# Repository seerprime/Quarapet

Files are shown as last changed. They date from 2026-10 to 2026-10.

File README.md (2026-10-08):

<div align="center">

# 🐾 QUARAPET

### An 8-servo, Wi-Fi-controlled, DIY quadruped robot with a face that has feelings.

*3D-printed. ESP32-S3 powered. Hand-soldered. Fully open source.*

<br>







<br>

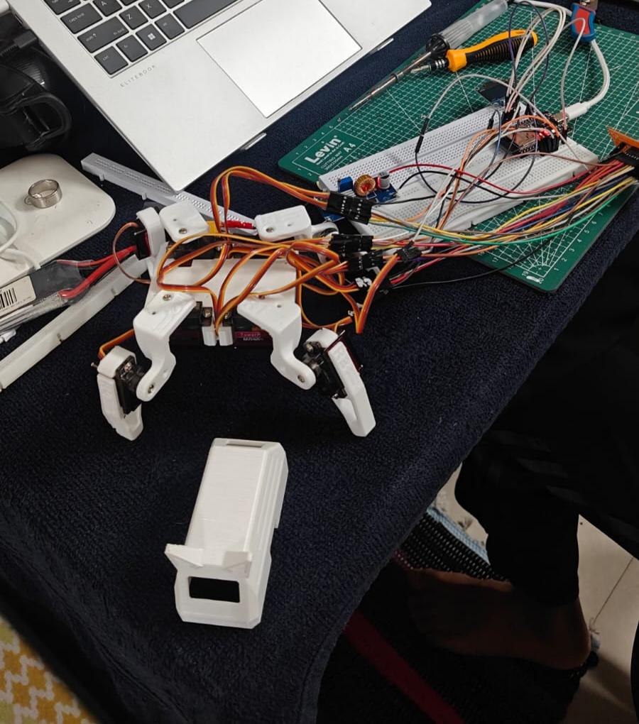
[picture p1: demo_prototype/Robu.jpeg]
Quarapet prototype on the workbench


<sub><i>The prototype mid-build: legs on, wires everywhere, laptop open. This is how it actually happens. 😄</i></sub>

<br><br>

**[🎬 Watch the demo](demo_prototype/prefinshed_build_demo.mp4)** &nbsp;•&nbsp;
**[⚡ Quick Start](#-quick-start)** &nbsp;•&nbsp;
**[🧰 Build Guide](#-build-it-yourself)** &nbsp;•&nbsp;
**[🎮 Controls](#-controls--moves)** &nbsp;•&nbsp;
**[🗂 Repo Map](#-repo-map)**

</div>

---

## 👀 What is Quarapet?

**Quarapet** is a pocket-sized four-legged robot pet that walks, dances, waves, does pushups, plays dead, and expresses its mood on a tiny OLED face.

Power it on and it spins up its **own Wi-Fi network**. Connect with your phone, a **captive portal pops open**, and you're driving a robot dog from your browser. No app, no Bluetooth pairing, no nonsense.

It's built to be **cheap, hackable, and buildable at home** with a 3D printer, a soldering iron, and a free weekend.

---

## ✨ Features

| | |
|---|---|
| 🦿 **8-DOF quadruped** | Two servos per leg for real walking, turning, and crab-stepping |
| 📡 **Self-hosted Wi-Fi AP** | Creates its own hotspot with a **captive portal**, so the control page auto-opens |
| 🏠 **Optional home Wi-Fi mode** | Join your own network from the web UI; reach it via `quarapet-robot.local` |
| 😎 **Animated OLED face** | 38 face sets with multi-frame animations: moods, talking variants, idle blinks |
| 🕺 **20+ built-in moves** | Walk, dance, wave, swim, pushup, bow, worm, moonwalk-ish chaos, and more |
| 🔌 **REST-style API** | `/api/command`, `/api/status`, `/api/wifi/*`, so you can script it or plug it into other things |
| 🎚️ **Live servo subtrim** | Calibrate each servo from the web UI without re-flashing |
| 🔋 **Battery powered** | Single 850 mAh LiPo, onboard switch, decoupling cap on the servo rail |
| 🖨️ **Fully printable** | Every structural part ships as an STL, with a cat-ear top cover 🐱 |

---

## 🎮 Controls & Moves

Everything is triggered from the web UI (or via `/cmd` and `/api/command`).

| Category | Commands |
|---|---|
| 🚶 **Locomotion** | `forward` · `backward` · `left` · `right` |
| 🧍 **Poses** | `stand` · `rest` · `dead` |
| 🎉 **Show-off** | `dance` · `wave` · `bow` · `cute` · `freaky` · `shake` · `shrug` |
| 💪 **Tricks** | `pushup` · `point` · `swim` · `worm` · `crab` |

### 😶 The Face Engine

The OLED isn't just a status light. It runs a frame-based animation system with **38 face sets**:

`happy` · `sad` · `angry` · `surprised` · `sleepy` · `love` · `excited` · `confused` · `thinking` · `idle` · `idle_blink` · plus a matching **`talk_*`** variant for each mood, and a face for every move (`walk`, `dance`, `wave`, `dead`, `crab`...).

When idle, Quarapet blinks on its own. When nobody's touched it for a while, it scrolls its Wi-Fi credentials across the screen so you never forget how to connect. 🙌

---

## ⚡ Quick Start

### 1. Flash the firmware

1. Install the **Arduino IDE** with the **ESP32 board package**.
2. Install these libraries from the Library Manager:
   - `ESP32Servo`
   - `Adafruit GFX Library`
   - `Adafruit SSD1306`
3. Open [`qurapet_firmware/sesame-firmware-main.ino`](qurapet_firmware/sesame-firmware-main.ino). The three `.h` files in the same folder load automatically.
4. Select your ESP32 board, pick the port, and hit **Upload**.

> ⚠️ **Check your pins!** The `servoPins[]` array near the top of the `.ino` is set for a specific board. If you wire to different GPIOs (see the [schematic](schematic/circuit_diagram.pdf)), update that array to match. Servo order is `R1, R2, L1, L2, R4, R3, L3, L4`.

### 2. Power on & connect

| | |
|---|---|
| 📶 **Wi-Fi name** | `quarapet` |
| 🔑 **Password** | `12345678` |
| 🌐 **Address** | `192.168.4.1` (the captive portal should open automatically) |

> 🔒 Change `AP_SSID` and `AP_PASS` in the firmware before you take it anywhere public.

### 3. Drive it 🚗

Tap a button. Watch it move. Smile at the tiny face. That's the whole product.

### 🏠 Want it on your home Wi-Fi?

Use the Wi-Fi setup panel in the web UI (it scans and connects at runtime), or set `NETWORK_SSID`, `NETWORK_PASS` and `ENABLE_NETWORK_MODE true` in the firmware. Then reach it at **`http://quarapet-robot.local`**.

---

## 🧰 Build It Yourself

### 1️⃣ Print the parts

All STLs live in [`cad_files/`](cad_files). Printed in white PLA in the prototype.

| Part | Files |
|---|---|
| 🦴 **Body frame** | `Internal-Frame-v121.stl` |
| 🔽 **Bottom cover** | `Bottom-Cover-v121.stl` |
| 🐱 **Top cover (cat ears!)** | `Top-Cover-Cat-v100.stl` |
| 🦵 **Left legs** | `L1` · `L2` · `L3` · `L4` (`-v117`) |
| 🦵 **Right legs** | `R1` · `R2` · `R3` · `R4` (`-v117`) |

### 2️⃣ Gather the parts

<details>
<summary><b>🔌 Electronics BOM</b> (click to expand)</summary>

<br>

| Component | Qty | Details |
|---|:---:|---|
| **TowerPro MG90S Servo** | 8 | Metal-gear micro servo |
| **ESP32-S3-N16R8** | 1 | Main controller |
| **LiPo Battery** | 1 | 850 mAh |
| **Power Switch** | 1 | ON/OFF |
| **OLED Display** | 1 | 0.96″ SSD1306 (I²C) |
| **Electrolytic Capacitor** | 1 | 100 µF, 25 V (10 V+ is fine) |

Full list: [`BOM/Electronics/parts.md`](BOM/Electronics/parts.md)

</details>

<details>
<summary><b>🔧 Tools & hardware BOM</b> (click to expand)</summary>

<br>

| Item | Spec |
|---|---|
| Phillips screws | M3 × 2.5 mm and M3 × 3 mm |
| Precision screwdriver kit | Multi-bit |
| Hot glue gun | Strain relief and wire fixing |
| Soldering iron + solder | Electronics grade |
| Perfboard | 5 × 7 cm |
| 3-pin headers | For servo connectors |

Full list with safety notes: [`BOM/mechanical_parts/mech_parts.md`](BOM/mechanical_parts/mech_parts.md)

</details>

### 3️⃣ Build the servo power board

Eight servos pull serious current, so they get a dedicated power rail with a bulk capacitor instead of leeching from the ESP32. The board is a simple perfboard distribution unit: **8 × 3-pin headers**, one shared **+ rail**, one shared **GND rail**, a **100 µF cap**, and a **2-pin power input**.

<div align="center">

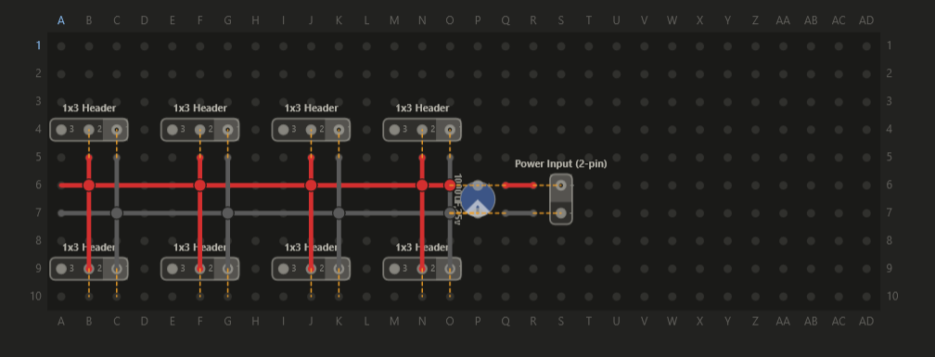
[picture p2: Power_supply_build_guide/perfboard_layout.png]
Perfboard layout for the servo power distribution board


<sub><i>Perfboard layout: red is +V, grey is GND. Follow the grid coordinates.</i></sub>

<br><br>

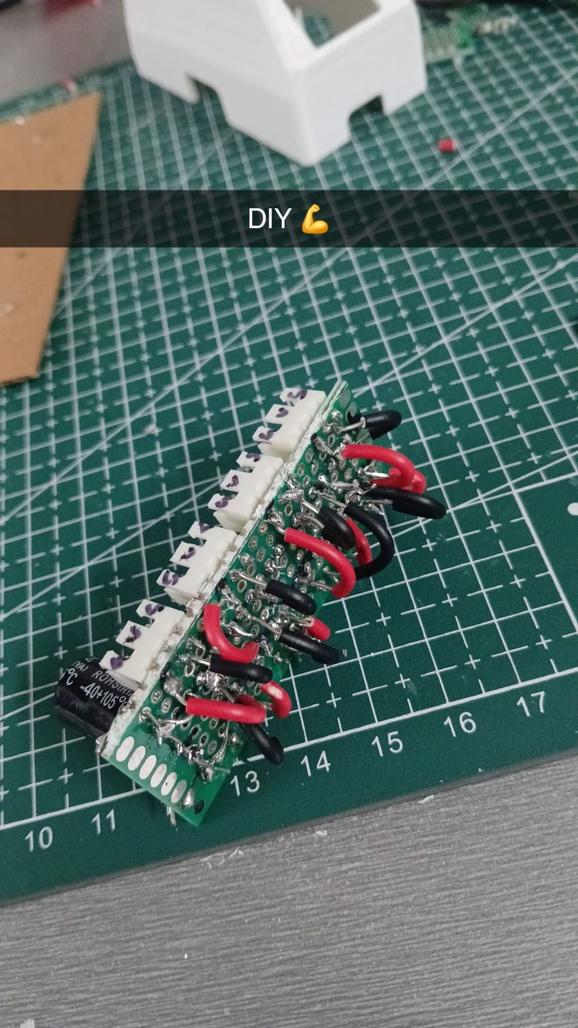
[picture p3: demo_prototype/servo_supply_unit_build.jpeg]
Finished hand-soldered servo supply board


<sub><i>The finished board, hand-soldered. Pure DIY. 💪</i></sub>

</div>

> 💡 **Golden rule:** servo power comes from the battery/regulated supply, **not** from the ESP32's 3.3 V pin. Servo GND and ESP32 GND **must be shared**.

### 4️⃣ Wire it up

Follow the full wiring diagram: **[`schematic/circuit_diagram.pdf`](schematic/circuit_diagram.pdf)**

| Connection | Pin |
|---|---|
| OLED **SDA** | GPIO 17 |
| OLED **SCL** | GPIO 18 |
| 8× servo signal | See `servoPins[]` in firmware |
| Servo V+ / GND | Perfboard power rail |

### 5️⃣ Assemble, flash, calibrate

1. Mount servos in the frame with the M3 screws.
2. Center all servos (run `stand`) *before* attaching the leg horns.
3. Fit the legs, tidy the wires, hot-glue the strain relief.
4. Close up with the cat-ear cover.
5. Fine-tune any crooked legs using **subtrim** in the web UI.

---

## 🎬 See It Move

<div align="center">

**[▶️ Click here to watch the prototype demo](demo_prototype/prefinshed_build_demo.mp4)**

</div>

---

## 🗂 Repo Map

```
Quarapet/
├── 📁 BOM/
│   ├── Electronics/parts.md          # Electronic components list
│   └── mechanical_parts/mech_parts.md # Tools, screws & materials
├── 📁 Power_supply_build_guide/
│   └── perfboard_layout.png          # Servo power board layout
├── 📁 cad_files/                     # 11 printable STL parts
├── 📁 demo_prototype/                # Build photos + demo video
├── 📁 qurapet_firmware/
│   ├── sesame-firmware-main.ino      # Main firmware: Wi-Fi, web server, servos
│   ├── movement-sequences.h          # Walk, dance, pushup & friends
│   ├── face-bitmaps.h                # OLED face animation frames
│   └── captive-portal.h              # Web control UI
└── 📁 schematic/
    └── circuit_diagram.pdf           # Full wiring schematic
```

---

## 🛠️ Hack It

- 🎨 **Add a new face:** add a bitmap to `face-bitmaps.h` and register it in `FACE_LIST`.
- 🕹️ **Add a new move:** write a `runYourPose()` in `movement-sequences.h` and hook it up in the command handler.
- 🤖 **Automate it:** hit `POST /api/command` from a script, a bot, or a smart-home hub.
- ⏱️ **Tune the feel:** tweak `frameDelay`, `walkCycles` and `motorCurrentDelay` for faster or smoother motion.

---

## 🧯 Safety

- Never solder with the battery connected.
- Use a stable iron stand and ventilate your workspace.
- Treat LiPo batteries with respect: no puncturing, no shorting, no unattended charging.
- Hot glue and soldering irons both burn. Be careful.

---

## 🤝 Contributing

Found a bug, improved a gait, or drew a better face? **PRs and issues are very welcome.** Fork it, break it, make it cooler. 🔥

---

## 🙏 Credits

Built with ❤️ by **[@seerprime](https://github.com/seerprime)**.
Thankyou **(https://github.com/dorianborian/sesame-robot/)** for inspiration
Shoutout to the open-source robotics and maker community whose quadruped designs and firmware ideas inspired this build.

---

<div align="center">

### ⭐ If Quarapet made you smile, drop a star! ⭐

*Build it. Break it. Make it yours.* 🐾

</div>

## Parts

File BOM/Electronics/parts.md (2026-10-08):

| Component | Quantity | Specification / Details |
|---|:---:|---|
| **TowerPro MG90S Servo** | 8 | Metal Gear Micro Servo |
| **ESP32-S3-N16R8** | 1 | Main controller |
| **LiPo Battery** | 1 | 850 mAh |
| **Power Switch** | 1 | ON/OFF switch |
| **OLED Display** | 1 | 0.96″ SSD1306 |
| **Electrolytic Capacitor** | 1 | 100 µF, 25 V *(10 V or higher is acceptable)* |

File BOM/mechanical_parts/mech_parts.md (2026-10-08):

# 🔧 Tools & Hardware

This section contains the tools, fasteners, and electronic assembly materials required for the project.

## 📋 Bill of Materials

| S. No. | Item | Specification / Size | Purpose |
|---:|---|---|---|
| 1 | Phillips Head Screw | **M3 × 2.5 mm** | Mounting and securing components |
| 2 | Phillips Head Screw | **M3 × 3 mm** | Mounting and securing components |
| 3 | Screwdriver Kit | Precision / Multi-bit | Tightening and loosening screws |
| 4 | Glue Gun | Standard hot-melt glue gun | Mechanical fixing and insulation |
| 5 | Soldering Wire | Electronics-grade solder | Electrical connections |
| 6 | Perfboard | **5 × 7 cm** | Permanent circuit assembly |
| 7 | 3-Pin Header | Male/Female, 3-pin | Connecting modules and components |
| 8 | Soldering Iron | Electronics soldering iron | Soldering electrical connections |

## 🛠️ Usage

### M3 × 2.5 mm & M3 × 3 mm Screws
Used for securing small mechanical components, brackets, servos, and structural parts.

### Screwdriver Kit
Used for assembling and disassembling the mechanical structure and tightening Phillips-head screws.

### Glue Gun
Used for:
- Securing loose wires
- Strain relief
- Holding lightweight components
- Additional mechanical support

### Soldering Wire & Soldering Iron
Used together to create permanent electrical connections between components mounted on the perfboard and headers.

### 5 × 7 cm Perfboard
Provides a compact platform for permanently mounting and interconnecting electronic components.

### 3-Pin Header
Used to provide detachable connections for sensors, servos, modules, or other peripherals.

## ⚠️ Safety Notes

- Allow the soldering iron to heat up on a stable stand.
- Avoid touching the soldering iron tip or recently soldered joints.
- Use adequate ventilation while soldering.
- Handle the hot glue gun carefully to avoid burns.
- Check screw lengths before installation to prevent damage to internal components.
- Disconnect the power supply before modifying or soldering the circuit.

## 📦 Assembly Checklist

- [ ] M3 × 2.5 mm screws
- [ ] M3 × 3 mm screws
- [ ] Screwdriver kit
- [ ] Glue gun
- [ ] Soldering wire
- [ ] 5 × 7 cm perfboard
- [ ] 3-pin headers
- [ ] Soldering iron

---
**Note:** These tools and materials are intended for the mechanical assembly and electrical integration of the project.

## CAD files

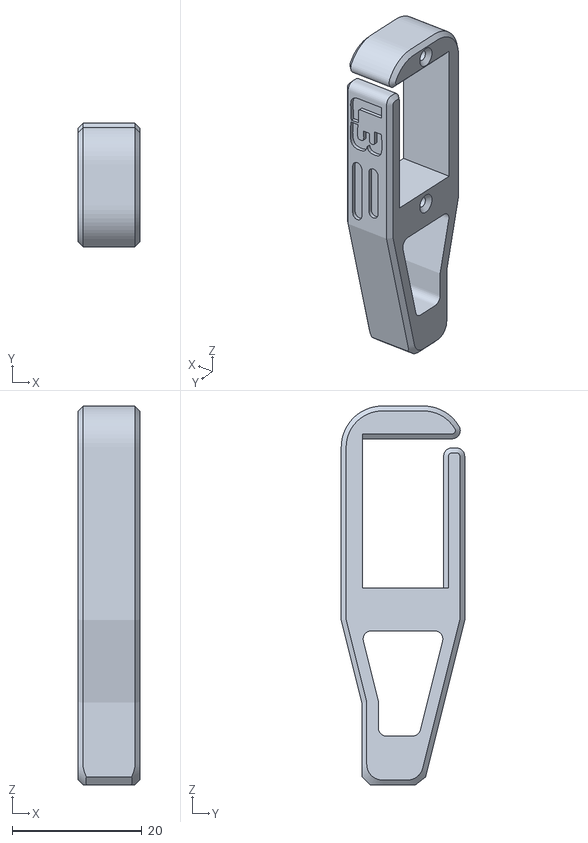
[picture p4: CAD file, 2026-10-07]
cad_files/L3-v117.stl
9.53 x 19.0 x 58.4

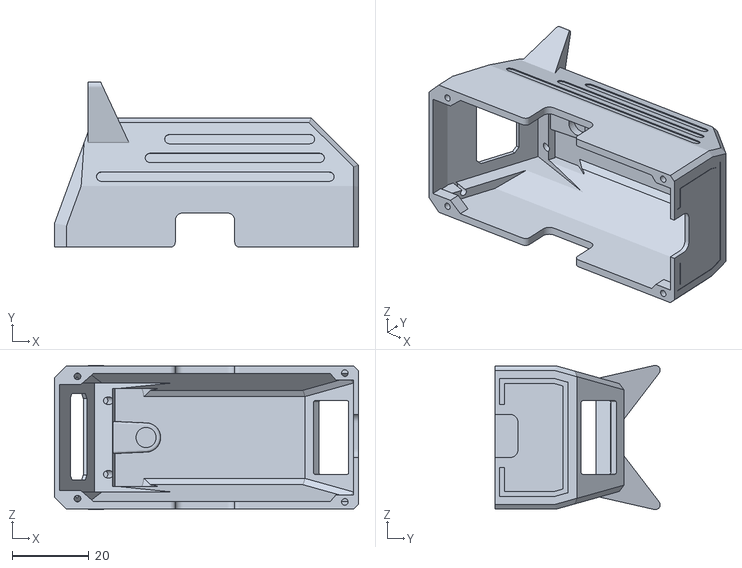
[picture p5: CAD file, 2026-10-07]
cad_files/Top-Cover-Cat-v100.stl
79.2 x 43.1 x 37.6

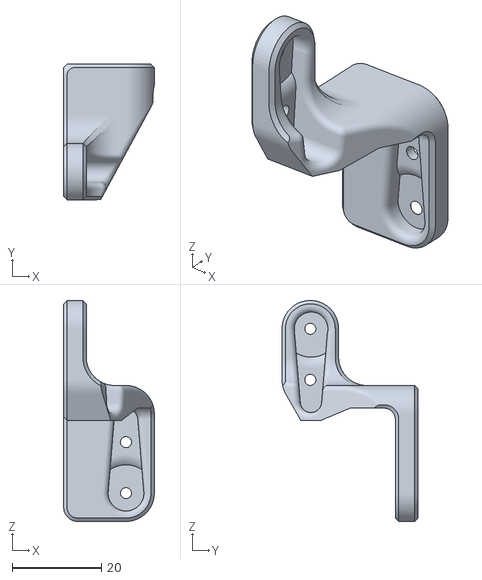
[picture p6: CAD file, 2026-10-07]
cad_files/L2-v117.stl
20.3 x 30.5 x 49.5

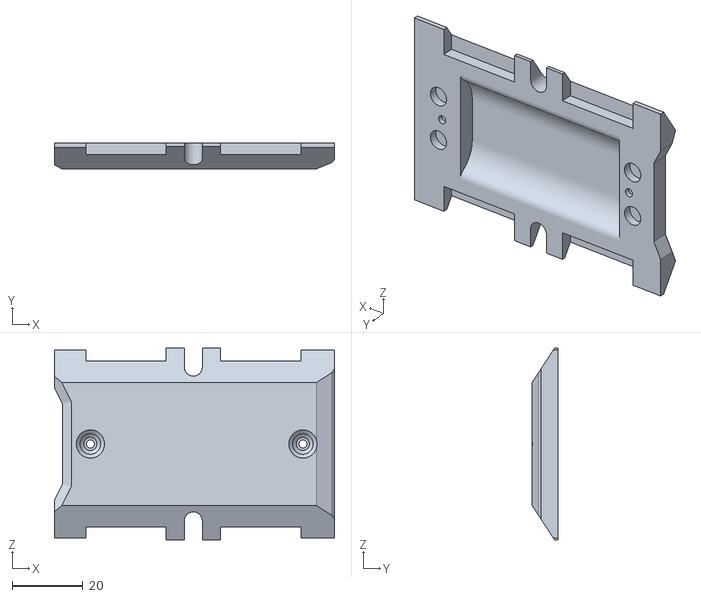
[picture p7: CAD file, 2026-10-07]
cad_files/Bottom-Cover-v121.stl
79.2 x 7.27 x 54.2

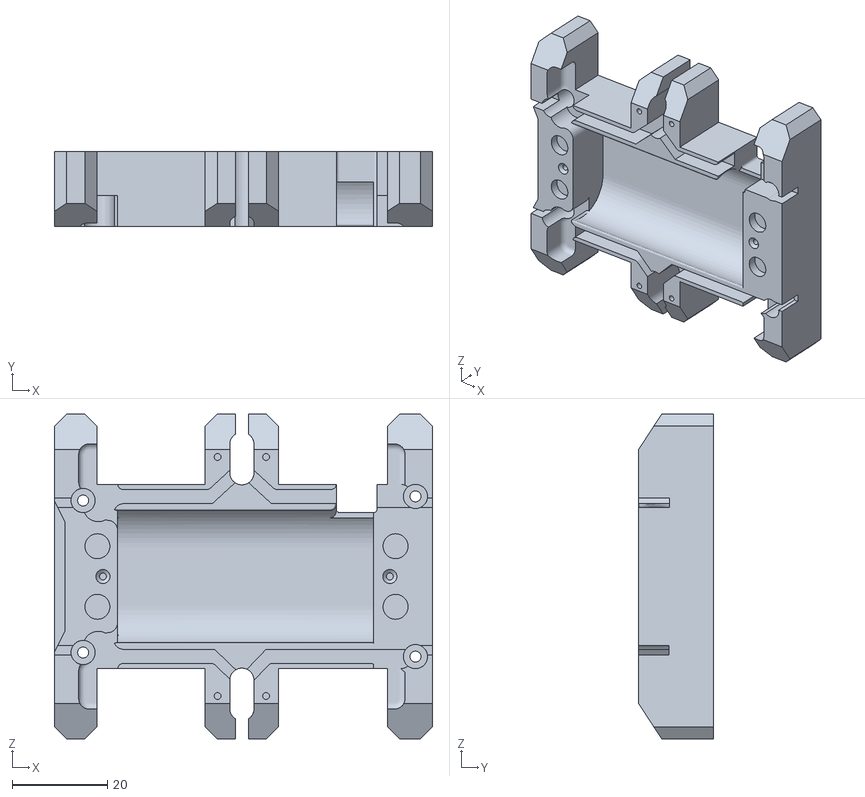
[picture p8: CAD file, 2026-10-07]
cad_files/Internal-Frame-v121.stl
79.2 x 15.7 x 68.1

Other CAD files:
cad_files/L4-v117.stl
cad_files/R3-v117.stl
cad_files/R4-v117.stl
cad_files/L1-v117.stl
cad_files/R2-v117.stl
cad_files/R1-v117 (1).stl

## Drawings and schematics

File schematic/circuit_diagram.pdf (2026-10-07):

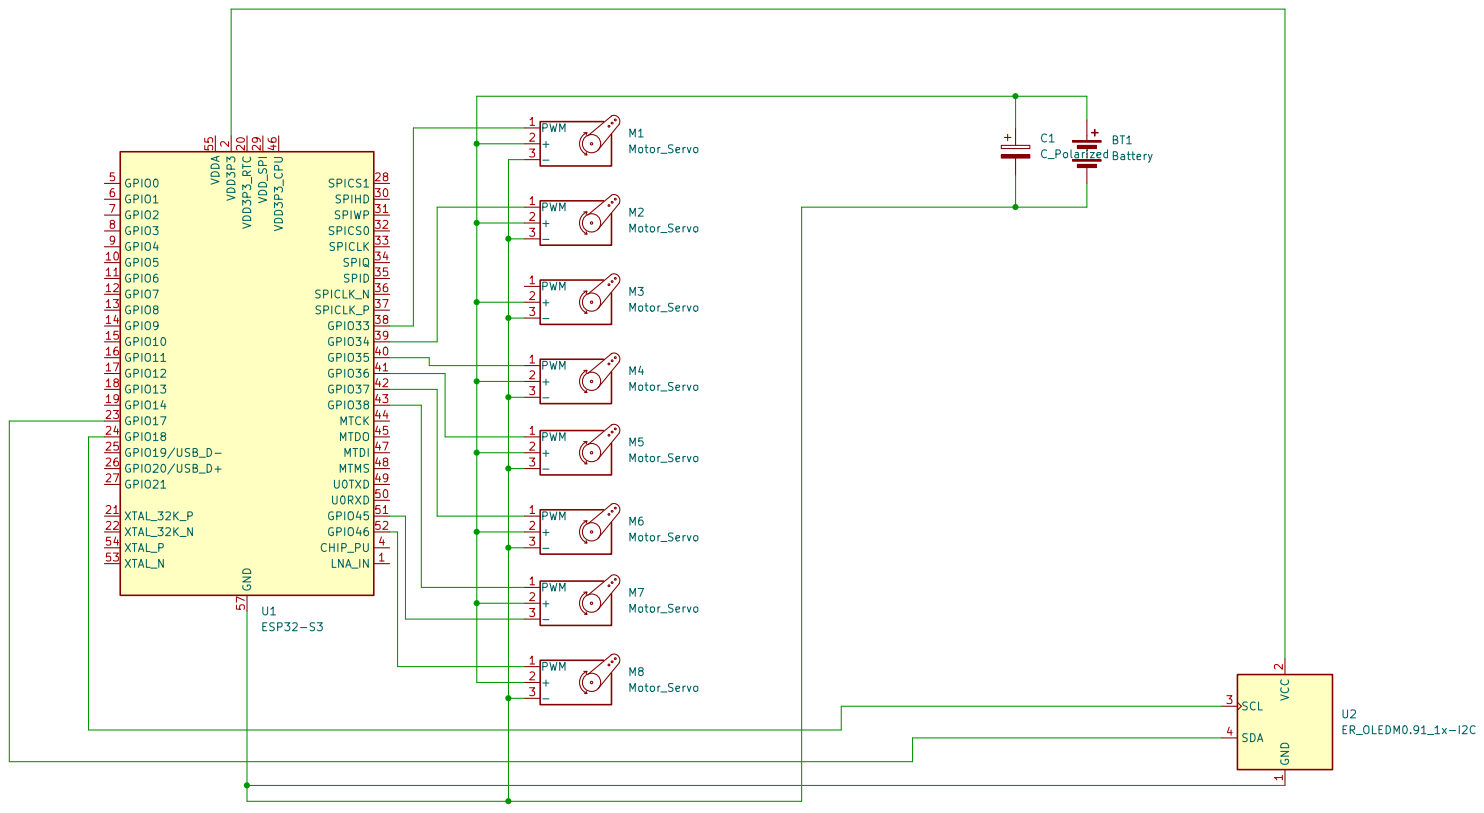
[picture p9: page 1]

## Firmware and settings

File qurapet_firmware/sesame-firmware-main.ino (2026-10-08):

#include <WiFi.h>
#include <WebServer.h>
#include <DNSServer.h>
#include <ESPmDNS.h>
#include <Wire.h>
#include <ESP32Servo.h>
#include <Adafruit_GFX.h>
#include <Adafruit_SSD1306.h>
#include "face-bitmaps.h"
#include "movement-sequences.h"
#include "captive-portal.h"
// --- Access Point Configuration ---
// This is the network the Robot will create
#define AP_SSID  "quarapet"
#define AP_PASS  "12345678" // Must be at least 8 characters
// --- Station Mode Configuration (Optional) ---
// Set these to connect to your home/office WiFi network
// Leave NETWORK_SSID empty to disable station mode
#define NETWORK_SSID ""  // Your WiFi network name
#define NETWORK_PASS ""  // Your WiFi password
#define ENABLE_NETWORK_MODE false  // Set to true to enable network connection attempts
#define SCREEN_WIDTH 128
#define SCREEN_HEIGHT 64
#define OLED_RESET -1
#define OLED_I2C_ADDR 0x3C
#define I2C_SDA 17
#define I2C_SCL 18
// DNS Server for Captive Portal
DNSServer dnsServer;
const byte DNS_PORT = 53;
Adafruit_SSD1306 display(SCREEN_WIDTH, SCREEN_HEIGHT, &Wire, OLED_RESET);
WebServer server(80);
// Global state for animations
String currentCommand = "";
String currentFaceName = "default";
const unsigned char* const* currentFaceFrames = nullptr;
uint8_t currentFaceFrameCount = 0;
uint8_t currentFaceFrameIndex = 0;
unsigned long lastFaceFrameMs = 0;
int faceFps = 8;
FaceAnimMode currentFaceMode = FACE_ANIM_LOOP;
int8_t faceFrameDirection = 1;
bool faceAnimFinished = false;
int currentFaceFps = 0;
bool idleActive = false;
bool idleBlinkActive = false;
unsigned long nextIdleBlinkMs = 0;
uint8_t idleBlinkRepeatsLeft = 0;
// WiFi Info Scrolling
unsigned long lastInputTime = 0;
bool firstInputReceived = false;
bool showingWifiInfo = false;
int wifiScrollPos = 0;
unsigned long lastWifiScrollMs = 0;
String wifiInfoText = "";
// Network Mode
bool networkConnected = false;
IPAddress networkIP;
String deviceHostname = "quarapet-robot";
bool mdnsOk = false;
// Runtime WiFi provisioning (web UI) — the connect attempt runs as a state
// machine driven from loop() so HTTP handlers never block the captive portal.
enum WifiSetupState { WIFI_SETUP_IDLE, WIFI_SETUP_QUEUED, WIFI_SETUP_CONNECTING };
WifiSetupState wifiSetupState = WIFI_SETUP_IDLE;
String wifiSetupSsid = "";
String wifiSetupPass = "";
String wifiSetupError = "";          // result of the last finished attempt ("" = none/success)
unsigned long wifiSetupQueuedMs = 0;
unsigned long wifiSetupStartMs = 0;
bool wifiRestoreApOnly = false;      // drop the station iface again after an AP-only scan
const uint32_t WIFI_CONNECT_TIMEOUT_MS = 15000;
const uint32_t WIFI_SETUP_START_DELAY_MS = 300;  // let the HTTP response flush before the AP channel may hop
// Servo Pins for Distro Board
// ======================================================================
// Pin numbers are coorisponding to the ESP32 GPIO pins and may differ based on which board you use.
// If you are using a different board, please adjust the servoPins array accordingly.
// ======================================================================
Servo servos[8];
// quarapet Distro Board V3 Pinout [NEW]
//const int servoPins[8] = {4, 5, 6, 7, 10, 11, 12, 13};
// quarapet Distro Board V2 Pinout (Legacy)
//const int servoPins[8] = {4, 5, 6, 7, 15, 16, 17, 18};
// quarapet Distro Board V1 Pinout (Legacy)
//const int servoPins[8] = {15, 2, 23, 19, 4, 16, 17, 18};
// Lolin S2 Mini Pinout
const int servoPins[8] = {1, 2, 4, 6, 8, 10, 13, 14};
// Subtrim values for each servo (offset in degrees)
int8_t servoSubtrim[8] = {0, 0, 0, 0, 0, 0, 0, 0};
// Animation constants
int frameDelay = 100;
int walkCycles = 10;
int motorCurrentDelay = 20; // ms delay between motor movements to prevent over-current
struct FaceEntry {
  const char* name;
  const unsigned char* const* frames;
  uint8_t maxFrames;
};
static const uint8_t MAX_FACE_FRAMES = 6;
#define MAKE_FACE_FRAMES(name) \
  const unsigned char* const face_##name##_frames[] = { \
    epd_bitmap_##name, epd_bitmap_##name##_1, epd_bitmap_##name##_2, \
    epd_bitmap_##name##_3, epd_bitmap_##name##_4, epd_bitmap_##name##_5 \
  };
#define X(name) MAKE_FACE_FRAMES(name)
FACE_LIST
#undef X
#undef MAKE_FACE_FRAMES
const FaceEntry faceEntries[] = {
#define X(name) { #name, face_##name##_frames, MAX_FACE_FRAMES },
  FACE_LIST
#undef X
  { "default", face_defualt_frames, MAX_FACE_FRAMES }
};
struct FaceFpsEntry {
  const char* name;
  uint8_t fps;
};
const FaceFpsEntry faceFpsEntries[] = {
  { "walk", 1 },
  { "rest", 1 },
  { "swim", 1 },
  { "dance", 1 },
  { "wave", 1 },
  { "point", 5 },
  { "stand", 1 },
  { "cute", 1 },
  { "pushup", 1 },
  { "freaky", 1 },
  { "bow", 1 },
  { "worm", 1 },
  { "shake", 1 },
  { "shrug", 1 },
  { "dead", 2 },
  { "crab", 1 },
  { "idle", 1 },
  { "idle_blink", 7 },
  { "default", 1 },
  // Conversational faces (manually controlled by Python - no auto-animation)
  { "happy", 1 },
  { "talk_happy", 1 },
  { "sad", 1 },
  { "talk_sad", 1 },
  { "angry", 1 },
  { "talk_angry", 1 },
  { "surprised", 1 },
  { "talk_surprised", 1 },
  { "sleepy", 1 },
  { "talk_sleepy", 1 },
  { "love", 1 },
  { "talk_love", 1 },
  { "excited", 1 },
  { "talk_excited", 1 },
  { "confused", 1 },
  { "talk_confused", 1 },
  { "thinking", 1 },
  { "talk_thinking", 1 },
};
// Prototypes
void setServoAngle(uint8_t channel, int angle);
void updateFaceBitmap(const unsigned char* bitmap);
void setFace(const String& faceName);
void setFaceMode(FaceAnimMode mode);
void setFaceWithMode(const String& faceName, FaceAnimMode mode);
void updateAnimatedFace();
void delayWithFace(unsigned long ms);
void enterIdle();
void exitIdle();
void updateIdleBlink();
int getFaceFpsForName(const String& faceName);
bool pressingCheck(String cmd, int ms);
void handleGetSettings();
void handleSetSettings();
void handleGetStatus();
void handleApiCommand();
void updateWifiInfoScroll();
void recordInput();
bool connectToWifi(const String& ssid, const String& pass, uint32_t timeoutMs = 10000);
void handleWifiScan();
void handleWifiConnect();
void handleWifiStatus();
void handleNotFound();
String jsonEscape(const String& s);
bool startMdns();
void announceNetwork(const String& ssid);
void setApOnlyInfoText();
void showWifiInfoNow();
void updateWifiSetup();
void finishWifiSetup(const String& err);
void handleRoot() {
  server.send(200, "text/html", index_html);
}
void handleCommandWeb() {
  // We send 200 OK immediately so the web browser doesn't hang waiting for animation to finish
  if (server.hasArg("pose")) {
    currentCommand = server.arg("pose");
    recordInput();
    exitIdle();
    server.send(200, "text/plain", "OK"); 
  } 
  else if (server.hasArg("go")) {
    currentCommand = server.arg("go");
    recordInput();
    exitIdle();
    server.send(200, "text/plain", "OK");
  } 
  else if (server.hasArg("stop")) {
    currentCommand = "";
    recordInput();
    server.send(200, "text/plain", "OK");
  }
  else if (server.hasArg("motor") && server.hasArg("value")) {
    int motorNum = server.arg("motor").toInt();
    int servoIdx = servoNameToIndex(server.arg("motor"));
    int angle = server.arg("value").toInt();
    if (motorNum >= 1 && motorNum <= 8 && angle >= 0 && angle <= 180) {
      setServoAngle(motorNum - 1, angle); // Convert 1-based to 0-based index
      recordInput();
      server.send(200, "text/plain", "OK");
    } else if (servoIdx != -1 && angle >= 0 && angle <= 180) {
      setServoAngle(servoIdx, angle);
      recordInput();
      server.send(200, "text/plain", "OK");
    } else {
      server.send(400, "text/plain", "Invalid motor or angle");
    }
  }
  else {
    server.send(400, "text/plain", "Bad Args");
  }
}
void handleGetSettings() {
  String json = "{";
  json += "\"frameDelay\":" + String(frameDelay) + ",";
  json += "\"walkCycles\":" + String(walkCycles) + ",";
  json += "\"motorCurrentDelay\":" + String(motorCurrentDelay) + ",";
  json += "\"faceFps\":" + String(faceFps);
  json += "}";
  server.send(200, "application/json", json);
}
void handleSetSettings() {
  if (server.hasArg("frameDelay")) frameDelay = server.arg("frameDelay").toInt();
  if (server.hasArg("walkCycles")) walkCycles = server.arg("walkCycles").toInt();
  if (server.hasArg("motorCurrentDelay")) motorCurrentDelay = server.arg("motorCurrentDelay").toInt();
  if (server.hasArg("faceFps")) faceFps = (int)max(1L, server.arg("faceFps").toInt());
  server.send(200, "text/plain", "OK");
}
// API endpoint for network clients to get robot status
void handleGetStatus() {
  String json = "{";
  json += "\"currentCommand\":\"" + currentCommand + "\",";
  json += "\"currentFace\":\"" + currentFaceName + "\",";
  json += "\"networkConnected\":" + String(networkConnected ? "true" : "false") + ",";
  json += "\"apIP\":\"" + WiFi.softAPIP().toString() + "\"";
  if (networkConnected) {
    json += ",\"networkIP\":\"" + networkIP.toString() + "\"";
  }
  json += "}";
  server.send(200, "application/json", json);
}
// API endpoint for network clients to send commands (JSON-based)
void handleApiCommand() {
  if (server.method() != HTTP_POST) {
    server.send(405, "application/json", "{\"error\":\"Method not allowed\"}");
    return;
  }
  String body = server.arg("plain");
  Serial.println("API Command received:");
  Serial.println(body);
  // Check for face-only command (no movement)
  int faceOnlyStart = body.indexOf("\"face\":\"");
  if (faceOnlyStart == -1) {
    faceOnlyStart = body.indexOf("\"face\": \"");
  }
  // If we have a face but no command field, it's face-only
  bool faceOnly = (faceOnlyStart > 0 && body.indexOf("\"command\":") == -1 && body.indexOf("\"command\": ") == -1);
  String command = "";
  String face = "";
  // Parse face
  if (faceOnlyStart > 0) {
    faceOnlyStart = body.indexOf("\"", faceOnlyStart + 6) + 1;
    int faceEnd = body.indexOf("\"", faceOnlyStart);
    if (faceEnd > faceOnlyStart) {
      face = body.substring(faceOnlyStart, faceEnd);
      Serial.print("Parsed face: ");
      Serial.println(face);
    }
  }
  // Parse command (if not face-only)
  if (!faceOnly) {
    int cmdStart = body.indexOf("\"command\":\"");
    if (cmdStart == -1) {
      cmdStart = body.indexOf("\"command\": \"");
    }
    if (cmdStart == -1) {
      Serial.println("Error: command field not found");
      server.send(400, "application/json", "{\"error\":\"Missing command field\"}");
      return;
    }
    cmdStart = body.indexOf("\"", cmdStart + 10) + 1;
    int cmdEnd = body.indexOf("\"", cmdStart);
    if (cmdEnd <= cmdStart) {
      Serial.println("Error: invalid command format");
      server.send(400, "application/json", "{\"error\":\"Invalid command format\"}");
      return;
    }
    command = body.substring(cmdStart, cmdEnd);
    Serial.print("Parsed command: ");
    Serial.println(command);
  }
  // Set face if provided
  if (face.length() > 0) {
    setFace(face);
  }
  // If face-only, just acknowledge
  if (faceOnly) {
    recordInput();
    server.send(200, "application/json", "{\"status\":\"ok\",\"message\":\"Face updated\"}");
    return;
  }
  // Execute command
  if (command == "stop") {
    currentCommand = "";
    recordInput();
    server.send(200, "application/json", "{\"status\":\"ok\",\"message\":\"Command stopped\"}");
  } else {
    currentCommand = command;
    recordInput();
    exitIdle();
    server.send(200, "application/json", "{\"status\":\"ok\",\"message\":\"Command executed\"}");
  }
}
// Escape a string for embedding in a JSON string literal. Handles backslash,
// double-quote, and control characters (SSIDs are arbitrary octets — a nearby
// network with a newline in its name must not break the whole response).
String jsonEscape(const String& s) {
  String out;
  out.reserve(s.length() + 8);
  for (unsigned int i = 0; i < s.length(); i++) {
    char c = s[i];
    if (c == '\\') out += "\\\\";
    else if (c == '"') out += "\\\"";
    else if ((uint8_t)c < 0x20) {
      char buf[8];
      snprintf(buf, sizeof(buf), "\\u%04x", (uint8_t)c);
      out += buf;
    } else out += c;
  }
  return out;
}
// Start (or restart, after MDNS.end()) the mDNS responder. Tracks the result
// in mdnsOk so the API can avoid advertising a .local name that won't resolve.
bool startMdns() {
  mdnsOk = MDNS.begin(deviceHostname.c_str());
  if (mdnsOk) {
    MDNS.addService("http", "tcp", 80);
    Serial.println("mDNS responder started: http://" + deviceHostname + ".local");
  } else {
    Serial.println("Error setting up mDNS responder!");
  }
  return mdnsOk;
}
// Post-join side effects shared by the boot path and the web provisioning
// path: re-announce mDNS on the new station interface and rebuild the OLED
// scroll text for the joined network.
void announceNetwork(const String& ssid) {
  MDNS.end();
  startMdns();
  wifiInfoText = "AP: " + String(AP_SSID) + " (" + WiFi.softAPIP().toString() +
                 ")  |  Network: " + ssid + " (" + networkIP.toString() + ") or " +
                 deviceHostname + ".local  |  ";
}
// OLED scroll text for AP-only operation (no station connection).
void setApOnlyInfoText() {
  wifiInfoText = "Connect to WiFi: " + String(AP_SSID) + "  |  Pass: " + String(AP_PASS) +
                 "  |  IP: " + WiFi.softAPIP().toString() + "  |  Captive Portal will auto-open!  |  ";
}
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
void loop() {
  // Process DNS requests for captive portal
  dnsServer.processNextRequest();
  server.handleClient();
  updateWifiSetup();
  updateAnimatedFace();
  updateIdleBlink();
  updateWifiInfoScroll();
  if (currentCommand != "") {
    String cmd = currentCommand;
    if (cmd == "forward") runWalkPose();
    else if (cmd == "backward") runWalkBackward();
    else if (cmd == "left") runTurnLeft();
    else if (cmd == "right") runTurnRight();
    else if (cmd == "rest") { runRestPose(); if (currentCommand == "rest") currentCommand = ""; }
    else if (cmd == "stand") { runStandPose(1); if (currentCommand == "stand") currentCommand = ""; }
    else if (cmd == "wave") runWavePose();
    else if (cmd == "dance") runDancePose();
    else if (cmd == "swim") runSwimPose();
    else if (cmd == "point") runPointPose();
    else if (cmd == "pushup") runPushupPose();
    else if (cmd == "bow") runBowPose();
    else if (cmd == "cute") runCutePose();
    else if (cmd == "freaky") runFreakyPose();
    else if (cmd == "worm") runWormPose();
    else if (cmd == "shake") runShakePose();
    else if (cmd == "shrug") runShrugPose();
    else if (cmd == "dead") runDeadPose();
    else if (cmd == "crab") runCrabPose();
  }
  // Serial CLI for debugging (can be used to diagnose servo position issues and wiring)
  if (Serial.available()) {
    static char command_buffer[32];
    static byte buffer_pos = 0;
    char c = Serial.read();
    if (c == '\n' || c == '\r') {
      if (buffer_pos > 0) {
        command_buffer[buffer_pos] = '\0';
        int motorNum, angle;
        recordInput();
        if(strcmp(command_buffer, "run walk") == 0 || strcmp(command_buffer, "rn wf") == 0) { currentCommand = "forward"; runWalkPose(); currentCommand = ""; }
        else if(strcmp(command_buffer, "rn wb") == 0) { currentCommand = "backward"; runWalkBackward(); currentCommand = ""; }
        else if(strcmp(command_buffer, "rn tl") == 0) { currentCommand = "left"; runTurnLeft(); currentCommand = ""; }
        else if(strcmp(command_buffer, "rn tr") == 0) { currentCommand = "right"; runTurnRight(); currentCommand = ""; }
        else if(strcmp(command_buffer, "run rest") == 0 || strcmp(command_buffer, "rn rs") == 0) runRestPose();
        else if(strcmp(command_buffer, "run stand") == 0 || strcmp(command_buffer, "rn st") == 0) runStandPose(1);
        else if(strcmp(command_buffer, "rn wv") == 0) { currentCommand = "wave"; runWavePose(); }
        else if(strcmp(command_buffer, "rn dn") == 0) { currentCommand = "dance"; runDancePose(); }
        else if(strcmp(command_buffer, "rn sw") == 0) { currentCommand = "swim"; runSwimPose(); }
        else if(strcmp(command_buffer, "rn pt") == 0) { currentCommand = "point"; runPointPose(); }
        else if(strcmp(command_buffer, "rn pu") == 0) { currentCommand = "pushup"; runPushupPose(); }
        else if(strcmp(command_buffer, "rn bw") == 0) { currentCommand = "bow"; runBowPose(); }
        else if(strcmp(command_buffer, "rn ct") == 0) { currentCommand = "cute"; runCutePose(); }
        else if(strcmp(command_buffer, "rn fk") == 0) { currentCommand = "freaky"; runFreakyPose(); }
        else if(strcmp(command_buffer, "rn wm") == 0) { currentCommand = "worm"; runWormPose(); }
        else if(strcmp(command_buffer, "rn sk") == 0) { currentCommand = "shake"; runShakePose(); }
        else if(strcmp(command_buffer, "rn sg") == 0) { currentCommand = "shrug"; runShrugPose(); }
        else if(strcmp(command_buffer, "rn dd") == 0) { currentCommand = "dead"; runDeadPose(); }
        else if(strcmp(command_buffer, "rn cb") == 0) { currentCommand = "crab"; runCrabPose(); }
        else if (strncmp(command_buffer, "face ", 5) == 0 || strncmp(command_buffer, "fc ", 3) == 0) {
          const char* faceName = (command_buffer[1] == 'c') ? command_buffer + 3 : command_buffer + 5;
          if (strlen(faceName) > 0) {
            currentCommand = "";
            setFace(String(faceName));
            Serial.print("Face set to ");
            Serial.println(faceName);
          } else {
            Serial.println("Usage: face <name>");
          }
        }
        else if (strcmp(command_buffer, "subtrim") == 0 || strcmp(command_buffer, "st") == 0) {
          Serial.println("Subtrim values:");
          for (int i = 0; i < 8; i++) {
            Serial.print("Motor "); Serial.print(i); Serial.print(": ");
            if (servoSubtrim[i] >= 0) Serial.print("+");
            Serial.println(servoSubtrim[i]);
          }
        }
        else if (strcmp(command_buffer, "subtrim save") == 0 || strcmp(command_buffer, "st save") == 0) {
          Serial.println("Copy and paste this into your code:");
          Serial.print("int8_t servoSubtrim[8] = {");
          for (int i = 0; i < 8; i++) {
            Serial.print(servoSubtrim[i]);
            if (i < 7) Serial.print(", ");
          }
          Serial.println("};");
        }
        else if (strncmp(command_buffer, "subtrim reset", 13) == 0 || strncmp(command_buffer, "st reset", 8) == 0) {
          for (int i = 0; i < 8; i++) servoSubtrim[i] = 0;
          Serial.println("All subtrim values reset to 0");
        }
        else if (strncmp(command_buffer, "subtrim ", 8) == 0 || strncmp(command_buffer, "st ", 3) == 0) {
          const char* params = (command_buffer[1] == 't') ? command_buffer + 3 : command_buffer + 8;
          int trimMotor, trimValue;
          if (sscanf(params, "%d %d", &trimMotor, &trimValue) == 2) {
            if (trimMotor >= 0 && trimMotor < 8) {
              if (trimValue >= -90 && trimValue <= 90) {
                servoSubtrim[trimMotor] = trimValue;
                Serial.print("Motor "); Serial.print(trimMotor); Serial.print(" subtrim set to ");
                if (trimValue >= 0) Serial.print("+");
                Serial.println(trimValue);
              } else {
                Serial.println("Subtrim value must be between -90 and +90");
              }
            } else {
              Serial.println("Invalid motor number (0-7)");
            }
          }
        }
        else if (strncmp(command_buffer, "all ", 4) == 0) {
             if (sscanf(command_buffer + 4, "%d", &angle) == 1) {
                 for (int i = 0; i < 8; i++) setServoAngle(i, angle);
                 Serial.print("All servos set to "); Serial.println(angle);
             }
        }
        else if (sscanf(command_buffer, "%d %d", &motorNum, &angle) == 2) {
             if (motorNum >= 0 && motorNum < 8) {
                 setServoAngle(motorNum, angle);
                 Serial.print("Servo "); Serial.print(motorNum); Serial.print(" set to "); Serial.println(angle);
             } else {
                 Serial.println("Invalid motor number (0-7)");
             }
        }
        buffer_pos = 0;
      }
    } else if (buffer_pos < sizeof(command_buffer) - 1) {
      command_buffer[buffer_pos++] = c;
    }
  }
}
// Function to update the robot's face
void updateFaceBitmap(const unsigned char* bitmap) {
  display.clearDisplay();
  display.drawBitmap(0, 0, bitmap, 128, 64, SSD1306_WHITE);
  display.display();
}
uint8_t countFrames(const unsigned char* const* frames, uint8_t maxFrames) {
  if (frames == nullptr || frames[0] == nullptr) return 0;
  uint8_t count = 0;
  for (uint8_t i = 0; i < maxFrames; i++) {
    if (frames[i] == nullptr) break;
    count++;
  }
  return count;
}
void setFace(const String& faceName) {
  if (faceName == currentFaceName && currentFaceFrames != nullptr) return;
  currentFaceName = faceName;
  currentFaceFrameIndex = 0;
  lastFaceFrameMs = 0;
  faceFrameDirection = 1;
  faceAnimFinished = false;
  currentFaceFps = getFaceFpsForName(faceName);
  currentFaceFrames = face_defualt_frames;
  currentFaceFrameCount = countFrames(face_defualt_frames, MAX_FACE_FRAMES);
  for (size_t i = 0; i < (sizeof(faceEntries) / sizeof(faceEntries[0])); i++) {
    if (faceName.equalsIgnoreCase(faceEntries[i].name)) {
      currentFaceFrames = faceEntries[i].frames;
      currentFaceFrameCount = countFrames(faceEntries[i].frames, faceEntries[i].maxFrames);
      break;
    }
  }
  if (currentFaceFrameCount == 0) {
    currentFaceFrames = face_defualt_frames;
    currentFaceFrameCount = countFrames(face_defualt_frames, MAX_FACE_FRAMES);
    currentFaceName = "default";
    currentFaceFps = getFaceFpsForName(currentFaceName);
  }
  if (currentFaceFrameCount > 0 && currentFaceFrames[0] != nullptr) {
    updateFaceBitmap(currentFaceFrames[0]);
  }
}
void setFaceMode(FaceAnimMode mode) {
  currentFaceMode = mode;
  faceFrameDirection = 1;
  faceAnimFinished = false;
}
void setFaceWithMode(const String& faceName, FaceAnimMode mode) {
  setFaceMode(mode);
  setFace(faceName);
}
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
